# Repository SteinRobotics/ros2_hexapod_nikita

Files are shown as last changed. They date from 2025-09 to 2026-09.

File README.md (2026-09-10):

# Nikita Hexapod Robot (Maker Project)

**⚠️ WARNING: This repository is under heavy development! Breaking changes, incomplete features, and experimental code are expected. Use at your own risk. Contributions, feedback, and ideas are welcome.**

Nikita is an open-source, modular hexapod robot platform for makers, tinkerers, and robotics enthusiasts. The project is built around ROS2 and aims to be a flexible playground for learning, hacking, and experimenting with robotics and human-machine interaction. 

## Features & Goals
- **Maker Focus**: Designed for hands-on experimentation, learning, and creative robotics projects.
- **ROS2 Native**: Modern robotics workflows and easy integration with other ROS2 packages.
- **Modular Architecture**: Movement, communication, HMI, teleoperation, servo control, and more
- **Speech Recognition & Synthesis**: Online/offline STT and TTS with caching.
- **Flexible Gait & Kinematics**: Advanced gait controller and kinematics for smooth, stable walking and body pose control.
- **Teleoperation**: Joystick and remote control support.
- **Extensive Launch & Config**: Launch files and configuration options for different hardware and scenarios.
- **Diagnostics & Services**: Systemd integration and ROS2 topics for monitoring and diagnostics.

## Project Structure
- `nikita_brain/`         — High-level behavior, action planning, and coordination
- `nikita_movement/`      — Gait, kinematics, and movement primitives
- `nikita_communication/` — Speech recognition, TTS, chatbot, and audio I/O
- `nikita_hmi/`           — Human-machine interface (OLED, relay control)
- `nikita_teleop/`        — Teleoperation (joystick, remote)
- `nikita_lidar/`         — LIDAR sensor integration
- `nikita_navigation/`    — 1D-lidar head-sweep navigation with obstacle avoidance
- `nikita_interfaces/`    — Custom ROS2 message and service definitions
- `nikita_bringup/`       — Launch and bringup scripts
- `nikita_doc/`           — Documentation, diagrams, and hardware info
- `nikita_utils/`         — Shared utilities, math helpers, and tests
- `nikita_description/`   — URDF/XACRO robot model for visualization and simulation
- `nikita_gazebo/`        — Gazebo Harmonic simulation (gz-sim 8.x)

## Quick Start (for Makers)
1. **Install Dependencies**
   ```bash
   PIP_BREAK_SYSTEM_PACKAGES=1 rosdep install --from-paths ~/Workspace/colcon_nikita --ignore-src -r -y
   git submodule update --init --recursive
   ```
   If you want the simplest setup, keep using the full-workspace install above. If you want to split machines, the current package layout already allows two practical ROS setups:

   **Robot / headless target**
   - Intended for the Raspberry Pi or onboard computer.
   - Keeps runtime, sensor, audio, and hardware nodes.
   - Skips GUI and Gazebo packages such as `rviz2`, `joint_state_publisher_gui`, `ros_gz_sim`, and controller GUI tooling.
   ```bash
   PIP_BREAK_SYSTEM_PACKAGES=1 rosdep install -r -y --ignore-src \
     --from-paths \
       ~/Workspace/colcon_nikita/src/ros2_hexapod_nikita/nikita_interfaces \
       ~/Workspace/colcon_nikita/src/ros2_hexapod_nikita/nikita_utils \
       ~/Workspace/colcon_nikita/src/ros2_hexapod_nikita/nikita_movement \
       ~/Workspace/colcon_nikita/src/ros2_hexapod_nikita/nikita_brain \
       ~/Workspace/colcon_nikita/src/ros2_hexapod_nikita/nikita_communication \
       ~/Workspace/colcon_nikita/src/ros2_hexapod_nikita/nikita_hmi \
       ~/Workspace/colcon_nikita/src/ros2_hexapod_nikita/nikita_lidar \
       ~/Workspace/colcon_nikita/src/ros2_hexapod_nikita/nikita_navigation \
       ~/Workspace/colcon_nikita/src/ros2_hexapod_nikita/nikita_teleop \
       ~/Workspace/colcon_nikita/src/ros2_hexapod_nikita/nikita_bringup

   colcon build --symlink-install --packages-up-to nikita_bringup
   ```

   **Remote PC / simulation and GUI tools**
   - Intended for Gazebo, RViz, URDF inspection, and desktop debugging.
   - Keeps shared logic packages plus the visualization/simulation packages.
   - Can skip robot-only hardware packages such as `nikita_hmi` and usually `nikita_bringup`.
   ```bash
   PIP_BREAK_SYSTEM_PACKAGES=1 rosdep install -r -y --ignore-src \
     --from-paths \
       ~/Workspace/colcon_nikita/src/ros2_hexapod_nikita/nikita_interfaces \
       ~/Workspace/colcon_nikita/src/ros2_hexapod_nikita/nikita_utils \
       ~/Workspace/colcon_nikita/src/ros2_hexapod_nikita/nikita_movement \
       ~/Workspace/colcon_nikita/src/ros2_hexapod_nikita/nikita_brain \
       ~/Workspace/colcon_nikita/src/ros2_hexapod_nikita/nikita_communication \
       ~/Workspace/colcon_nikita/src/ros2_hexapod_nikita/nikita_navigation \
       ~/Workspace/colcon_nikita/src/ros2_hexapod_nikita/nikita_description \
       ~/Workspace/colcon_nikita/src/ros2_hexapod_nikita/nikita_gazebo

   colcon build --symlink-install \
     --packages-up-to nikita_gazebo nikita_description nikita_navigation
   ```

   Notes:
   - The split is already possible because the GUI-heavy dependencies are isolated mainly in `nikita_description` and `nikita_gazebo`, while `nikita_bringup` stays on the robot/runtime side.
   - Do not run `rosdep install --from-paths ...` over the entire workspace on the robot if you want a lean headless install, because that will pull the Gazebo and RViz dependencies too.
   - This is currently a documentation-level split, not a fully formalized profile system. If you later want stricter separation, the next step would be to introduce dedicated metapackages such as `nikita_robot` and `nikita_desktop`.
2. **Build the Workspace**
   ```bash
   colcon build --symlink-install
   source install/local_setup.bash
   ```
3. **Launch the Robot**
   ```bash
   ros2 launch nikita_bringup target_launch.py
   # with navigation enabled
   ros2 launch nikita_bringup target_launch.py enable_navigation:=true
   # or for testing
   ros2 launch nikita_bringup test_launch.py
   ```
4. **Launch Individual Components**
   ```bash
   ros2 launch nikita_brain brain_launch.py
   ros2 launch nikita_communication communication_launch.py
   ros2 launch nikita_movement movement_launch.py
   ros2 launch nikita_teleop teleop_launch.py
   ros2 launch nikita_lidar lidar_launch.yaml
   ros2 launch nikita_navigation navigation_launch.py
   # with map server
   ros2 launch nikita_navigation navigation_launch.py enable_map:=true
   ```
5. **Interact & Hack**
   - Send movement commands:
     ```bash
     ros2 topic pub --once /cmd_movement nikita_interfaces/msg/MovementRequest "..."
     ```
   - Monitor topics:
     ```bash
     ros2 topic list
     ros2 topic echo /servos_status
     ```
   - Speech commands:
     ```bash
     ros2 topic pub --once /speech_recognition_online std_msgs/msg/String "{data: 'steh auf'}"
     ```
   - Joystick/teleop:
     ```bash
     ros2 topic pub --once /joystick_request nikita_interfaces/msg/JoystickRequest "..."
     ```

## Simulation & Visualization

### Preview the Robot Model in RViz
Visualize the URDF model with interactive joint sliders — no Gazebo or hardware needed:
```bash
source install/setup.bash
ros2 launch nikita_description display.launch.py
```

To preview the CAD/STL-based model instead, use its separate launch file:
```bash
ros2 launch nikita_description display_mesh.launch.py
```
The original primitive model remains available through `display.launch.py`.

### Gazebo Simulation
Run the full hexapod simulation in Gazebo Harmonic:
```bash
# Install simulation dependencies (once)
sudo apt-get install ros-jazzy-gz-ros2-control ros-jazzy-controller-manager \
  ros-jazzy-joint-state-broadcaster ros-jazzy-forward-command-controller \
  ros-jazzy-joint-state-publisher-gui

# Navigation dependencies (optional)
sudo apt-get install ros-jazzy-nav2-map-server ros-jazzy-nav2-lifecycle-manager

# Build and launch
colcon build --symlink-install --packages-select nikita_description nikita_gazebo
source install/setup.bash
ros2 launch nikita_gazebo gazebo.launch.py

# Launch with the simple room world and navigation
ros2 launch nikita_gazebo simulation_gazebo.launch.py \
  world:=$(ros2 pkg prefix nikita_gazebo)/share/nikita_gazebo/worlds/simple_room.sdf \
  enable_navigation:=true
```

### Mesh Model in Gazebo
The mesh model has its own launch file and does not change the existing primitive-model simulation:
```bash
colcon build --symlink-install --packages-select nikita_description nikita_gazebo
source install/setup.bash
ros2 launch nikita_gazebo simulation_mesh.launch.py
```
This starts Gazebo Harmonic, spawns the STL-based robot, loads the existing 20-joint
controller configuration, and starts the joint-state broadcaster. The mesh model omits
head visuals but retains invisible head yaw and pitch joints for controller compatibility.

Command joints in the simulation (all 20 joints, values in radians):
```bash
ros2 topic pub /forward_position_controller/commands std_msgs/msg/Float64MultiArray \
  "{data: [0,0,0, 0,0,0, 0,0,0, 0,0,0, 0,0,0, 0,0,0, 0,0]}"
```

## Raspberry Pi 5 Pin Layout
The Raspberry Pi 5 inside Nikita hosts most of the human-machine interface hardware that lives in `nikita_hmi/`. The table follows the standard 40-pin header (odd numbers on the left when the USB ports face you). Pins with descriptions are currently wired up; empty cells are free for experiments.

| Pin | Signal | Usage | Pin | Signal | Usage |
| ----- | --- | --- | --- | --- | --- |
| **1** | 3V3 | supply for I2C modules | 2 | 5V | — |
| **3** | GPIO2 (SDA1)  | I2C bus | **4**  | 5V | Servo Power Relay |
| **5** | GPIO3 (SCL1)  | I2C bus | **6**  | GND | GND for I2C modules |
| 7 | GPIO4 | — | 8 | GPIO14 (TXD)  | — |
| 9 | GND | — | 10 | GPIO15 (RXD)  | — |
| 11 | GPIO17 | — | 12 | GPIO18 | — |
| 13 | GPIO27 | — | **14** | GND | Servo Power Relay |
| 15 | GPIO22 | — | 16 | GPIO23 | |
| 17 | 3V3 | — | 18 | GPIO24 | — |
| 19 | GPIO10 (MOSI) | — | 20 | GND | — |
| 21 | GPIO9 (MISO)  | — | 22 | GPIO25 | — |
| 23 | GPIO11 (SCLK) | — | 24 | GPIO8 (CE0) | — |
| 25 | GND | — | 26 | GPIO7 (CE1) | — |
| 27 | GPIO0 (ID_SD) | — | 28 | GPIO1 (ID_SC) | — |
| 29 | GPIO5 | — | 30 | GND | — |
| 31 | GPIO6 | — | 32 | GPIO12 | — |
| 33 | GPIO13 | — | **34** | GND | BNO055 I2C switch |
| 35 | GPIO19 | — | **36** | GPIO16 | Servo Power Relay |
| 37 | GPIO26 | — | 38 | GPIO20 | — |
| 39 | GND | — | 40 | GPIO21 | — |

### I2C Device Addresses
| Device | Address |
| --- | --- |
| BNO055 IMU | 0x29 |
| SSD1306 OLED Display | 0x3C |
| INA228 Power Monitor | 0x40 |
| Garmin Lidar Lite | 0x62 |

## Systemd Service (Optional)
To auto-start ROS2 on boot:
```bash
sudo systemctl start autostart_ros2
sudo systemctl status autostart_ros2
```

## Documentation
- See `nikita_doc/` for hardware pinouts, protocol docs, and setup guides.
- Diagrams and images are provided for wiring and architecture overview.

## Music
https://www.musicfox.com/info/kostenlose-gemafreie-musik/

## Contributing
This is a maker project—experimentation, hacking, and learning are encouraged! Contributions, bug reports, and feature requests are welcome. Please open issues or pull requests for improvements.

## License
Copyright (c) 2021-2025 Christian Stein

---

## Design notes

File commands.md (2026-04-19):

## service
```
sudo systemctl start autostart_ros2
sudo systemctl status autostart_ros2
```

## install dependencies
```
PIP_BREAK_SYSTEM_PACKAGES=1 rosdep install --from-paths ~/Workspace/colcon_nikita --ignore-src -r -y

python3 -m pip install lewansoul-lx16a --break-system-packages
python3 -m pip install lewansoul-lx16a-terminal --break-system-packages

git submodule update --init
```

## build
```
colcon build --symlink-install
colcon build --packages-up-to nikita_servo
```

```
source install/local_setup.bash
```

## log topics
```
ros2 topic list
ros2 topic echo --csv /servos_status
ros2 topic echo --once /servos_status
```

## send requests
```
ros2 topic pub --once /request_listening std_msgs/msg/Bool data:\ true

ros2 topic pub --once /speech_recognition_online std_msgs/msg/String data:\ "lauf nach vorne"

ros2 topic pub --once /speech_recognition_online std_msgs/msg/String "{data: 'steh auf'}"

ros2 topic pub --once /speech_recognition_online std_msgs/msg/String "{data: 'leg dich hin'}"

ros2 topic pub --once /speech_recognition_online std_msgs/msg/String data:\ "teste beine"

ros2 topic pub --once /request_music std_msgs/msg/String "{data: 'musicfox_hot_dogs_for_breakfast.mp3'}"

ros2 topic pub --once /joystick_request nikita_interfaces/msg/JoystickRequest "header:
  stamp:
    sec: 0
    nanosec: 0
  frame_id: ''
button_a: false
button_b: false
button_x: false
button_y: false
button_l1: false
button_l2: false
button_r1: false
button_r2: false
button_select: false
button_start: false
button_home: false
button_long_a: false
button_long_b: false
button_long_x: false
button_long_y: false
button_long_l1: false
button_long_l2: false
button_long_r1: false
button_long_r2: false
button_long_select: false
button_long_start: false
button_long_home: false
dpad_vertical: 0
dpad_horizontal: 0
left_stick_vertical: 0.50
left_stick_horizontal: 0.0
right_stick_horizontal: 0.0
right_stick_vertical: 0.0"
---

ros2 topic pub --once /cmd_vel geometry_msgs/msg/Twist "{linear: {x: 0.5, y: 0.0, z: 0.0}, angular: {x: 0.0, y: 0.0, z: 0.3}}"
---

ros2 topic pub --once /cmd_movement nikita_interfaces/msg/MovementRequest "header:
  stamp:
    sec: 0
    nanosec: 0
  frame_id: ''
type: 13
direction: 0
duration_s: 2.0
name: 'SEQUENCE_BODY_ROLL'
"
---

ros2 topic pub --once /cmd_movement nikita_interfaces/msg/MovementRequest "header:
  stamp:
    sec: 0
    nanosec: 0
  frame_id: ''
type: 4
direction: 0
duration_s: 1.0
name: ''
"

ros2 topic pub --once /cmd_movement nikita_interfaces/msg/MovementRequest "header:
  stamp:
    sec: 0
    nanosec: 0
  frame_id: ''
type: 20
direction: 0
duration_s: 1.0
name: 'CONTINUOUS_RUNNING'
"

ros2 topic pub --once /cmd_movement_update nikita_interfaces/msg/ContinuousMovementUpdate "header:
  stamp:
    sec: 0
    nanosec: 0
  frame_id: ''
velocity:
  linear: {x: 0.5, y: 0.0, z: 0.0}
  angular: {x: 0.0, y: 0.0, z: 0.0}
body_pose:
  position: {x: 0.0, y: 0.0, z: 0.0}
  orientation: {roll: 0.0, pitch: 0.0, yaw: 0.0}
head_orientation: {roll: 0.0, pitch: 0.0, yaw: 0.0}
"
---

ros2 topic echo --once /movement_type_actual
---

ros2 topic pub --once /servo_status nikita_interfaces/msg/ServoStatus "header:
  stamp:
    sec: 0
    nanosec: 0
  frame_id: ''
servo_error_code: 'LEG_LEFT_FRONT_COXA'
error_code: 0
servo_max_temperature: 'LEG_LEFT_FRONT_COXA'
max_temperature: 40.0
servo_max_voltage: 'LEG_LEFT_FRONT_COXA'
max_voltage: 12.0
servo_min_voltage: 'LEG_LEFT_FRONT_COXA'
min_voltage: 12.0
"
---

```
ros2 topic pub --once /single_servo_request nikita_interfaces/msg/ServoAngle "
  name: LEG_RIGHT_BACK_COXA 
  angle_deg: 0.0"
```

## launch robot
```
source install/local_setup.bash
ros2 launch nikita_bringup target_launch.py
ros2 launch nikita_bringup test_launch.py

ros2 launch nikita_brain brain_launch.py
ros2 launch nikita_communication communication_launch.py
ros2 launch nikita_movement movement_launch.py
ros2 launch nikita_servo servo_launch.py
ros2 launch nikita_teleop teleop_launch.py
ros2 launch nikita_lidar lidar_launch.yaml

#ros2 launch nikita_servo_controller servo_controller_launch.py

```

## remote computer

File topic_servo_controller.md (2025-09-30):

# topics of the node servo_controller 
```

ros2 topic pub --once /servo_status nikita_interfaces/msg/ServoStatus "header:
  stamp:
    sec: 0
    nanosec: 0
  frame_id: ''
servo_error_code: 'LEG_LEFT_FRONT_COXA'
error_code: 0
servo_max_temperature: 'LEG_LEFT_FRONT_COXA'
max_temperature: 40.0
servo_max_voltage: 'LEG_LEFT_FRONT_COXA'
max_voltage: 12.0
servo_min_voltage: 'LEG_LEFT_FRONT_COXA'
min_voltage: 12.0
"
```

## servo direct request
### set Servo ID
```
ros2 topic pub --once /servo_direct_request nikita_interfaces/msg/ServoDirectRequest "
name: 'LEG_LEFT_FRONT_COXA'
cmd: 13
data1: 10
data2: 0
"
```

ros2 topic pub --once /servo_request nikita_interfaces/msg/ServoRequest "header:
  stamp:
    sec: 0
    nanosec: 0
  frame_id: ''
target_angles:
- name: 'HEAD_YAW'
  angle_deg: 0.0
- name: 'HEAD_PITCH'
  angle_deg: 0.0
- name: 'LEG_LEFT_FRONT_COXA'
  angle_deg: 0.0
- name: 'LEG_LEFT_FRONT_FEMUR'
  angle_deg: 20.0
- name: 'LEG_LEFT_FRONT_TIBIA'
  angle_deg: 20.0
- name: 'LEG_LEFT_MID_COXA'
  angle_deg: 0.0
- name: 'LEG_LEFT_MID_FEMUR'
  angle_deg: 0.0
- name: 'LEG_LEFT_MID_TIBIA'
  angle_deg: 0.0
- name: 'LEG_LEFT_BACK_COXA'
  angle_deg: 0.0
- name: 'LEG_LEFT_BACK_FEMUR'
  angle_deg: 0.0
- name: 'LEG_LEFT_BACK_TIBIA'
  angle_deg: 0.0
- name: 'LEG_RIGHT_FRONT_COXA'
  angle_deg: 0.0
- name: 'LEG_RIGHT_FRONT_FEMUR'
  angle_deg: 0.0
- name: 'LEG_RIGHT_FRONT_TIBIA'
  angle_deg: 0.0
- name: 'LEG_RIGHT_MID_COXA'
  angle_deg: 0.0
- name: 'LEG_RIGHT_MID_FEMUR'
  angle_deg: 0.0
- name: 'LEG_RIGHT_MID_TIBIA'
  angle_deg: 0.0
- name: 'LEG_RIGHT_BACK_COXA'
  angle_deg: 0.0
- name: 'LEG_RIGHT_BACK_FEMUR'
  angle_deg: 0.0
- name: 'LEG_RIGHT_BACK_TIBIA'
  angle_deg: 0.0
time_to_reach_target_angles_ms: 3000"
```

```
ros2 topic pub --once /single_servo_request nikita_interfaces/msg/ServoAngle "
  name: LEG_RIGHT_BACK_COXA 
  angle_deg: 0.0"
```

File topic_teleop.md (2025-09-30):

# send requests

## stehe auf:
```
ros2 topic pub --once /joystick_request nikita_interfaces/msg/JoystickRequest "header:
  stamp:
    sec: 0
    nanosec: 0
  frame_id: ''
button_a: false
button_b: false
button_x: false
button_y: false
button_l1: false
button_l2: false
button_r1: false
button_r2: false
button_select: false
button_start: false
dpad_vertical: 1
dpad_horizontal: 0
left_stick_vertical: 0.0
left_stick_horizontal: 0.0
right_stick_horizontal: 0.0
right_stick_vertical: 0.0"
```

## cyclic movement
```
ros2 topic pub --rate 10 /joystick_request nikita_interfaces/msg/JoystickRequest "header:
  stamp:
    sec: 0
    nanosec: 0
  frame_id: ''
button_a: false
button_b: false
button_x: false
button_y: false
button_l1: false
button_l2: false
button_r1: false
button_r2: false
button_select: false
button_start: false
dpad_vertical: 0
dpad_horizontal: 0
left_stick_vertical: 0.4
left_stick_horizontal: 0.0
right_stick_horizontal: 0.0
right_stick_vertical: 0.0"
```
```
ros2 topic pub --once /joystick_request nikita_interfaces/msg/JoystickRequest "header:
  stamp:
    sec: 0
    nanosec: 0
  frame_id: ''
button_a: false
button_b: false
button_x: false
button_y: false
button_l1: false
button_l2: false
button_r1: false
button_r2: false
button_select: false
button_start: false
dpad_vertical: 0
dpad_horizontal: 0
left_stick_vertical: 0.0
left_stick_horizontal: 0.0
right_stick_horizontal: 0.0
right_stick_vertical: 0.0"
```

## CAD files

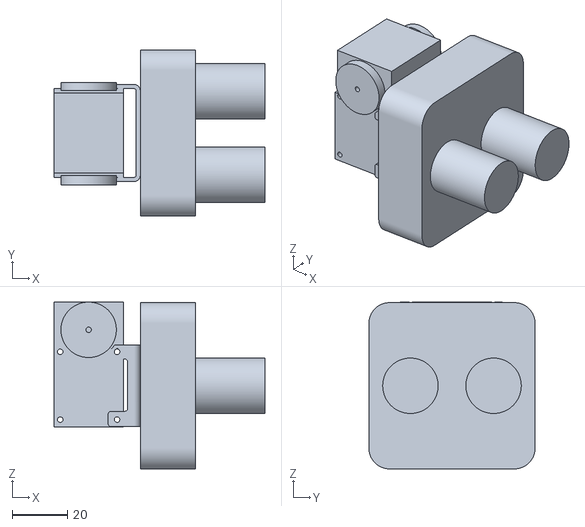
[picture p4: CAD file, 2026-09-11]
nikita_description/meshes/assembly_head.stl
76.1 x 60.0 x 60.2

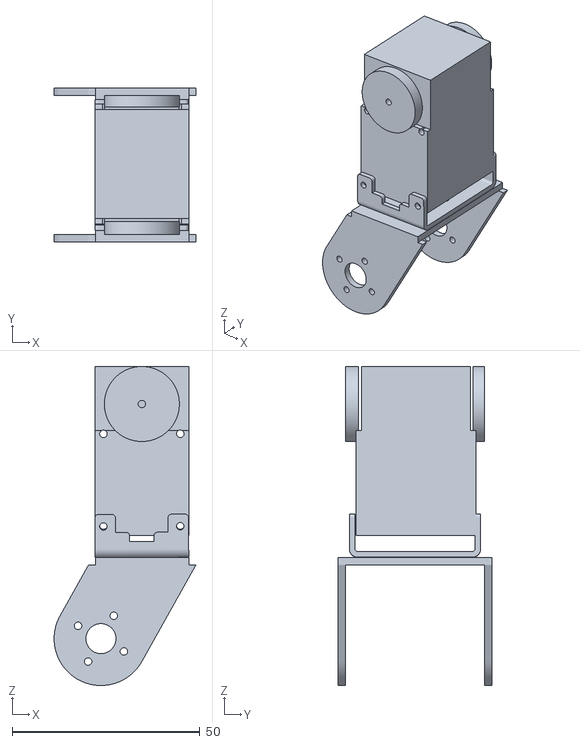
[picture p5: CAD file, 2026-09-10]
nikita_description/meshes/assembly_femur.stl
37.8 x 41.0 x 85.1

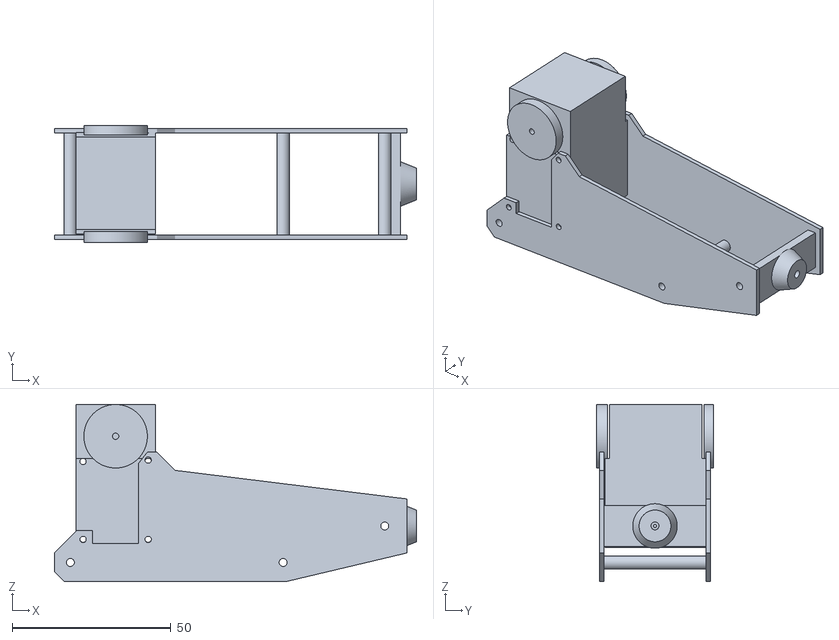
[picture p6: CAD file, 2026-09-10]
nikita_description/meshes/assembly_tibia.stl
114.0 x 37.0 x 55.8

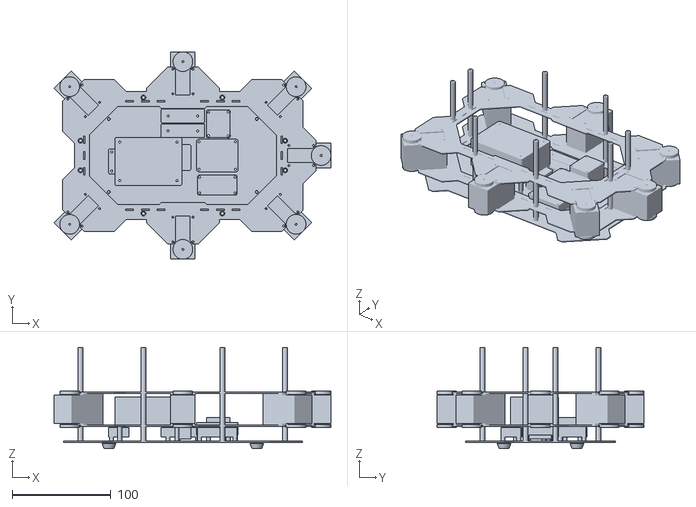
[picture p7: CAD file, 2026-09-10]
nikita_description/meshes/assembly_body_servo.stl
280.9 x 210.4 x 102.5

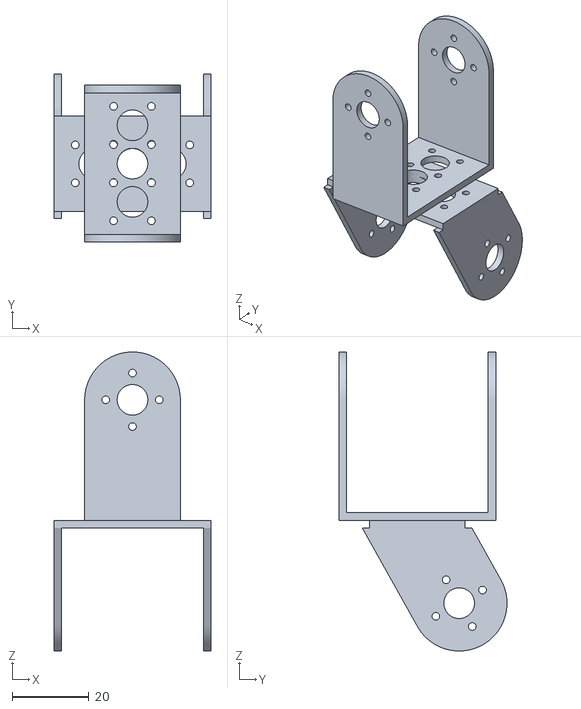
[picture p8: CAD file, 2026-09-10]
nikita_description/meshes/assembly_coxa.stl
41.0 x 43.9 x 78.1

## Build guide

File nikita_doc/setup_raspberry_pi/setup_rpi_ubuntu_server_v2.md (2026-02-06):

# Initial Setup
## WiFi Connection
```
sudo cat /etc/netplan/50-cloud-init.yaml
__
network:
  version: 2
  wifis:
    wlan0:
      optional: true
      dhcp4: true
      access-points:
        "XXXXXXXXXXXX":
          auth:
            key-management: "psk"
            password: "YYYYYYYYYYYYY"
        "InnoWorX_1":
          password: "AAAAAA"
        "ChristianHotspot":
          password: "AAAAAA"

__

sudo apt update
sudo apt upgrade
sudo reboot
sudo shutdown -h now
mkdir Workspace
```

____
## install Workspace
### install ROS2
```
mkdir colcon_nikita
cd colcon_nikita/
mkdir src
cd src/
locale  # check for UTF-8
sudo apt update && sudo apt install locales
sudo locale-gen en_US en_US.UTF-8
sudo update-locale LC_ALL=en_US.UTF-8 LANG=en_US.UTF-8
export LANG=en_US.UTF-8
locale  # verify settings
sudo apt install software-properties-common
sudo add-apt-repository universe
sudo apt update && sudo apt install curl -y
export ROS_APT_SOURCE_VERSION=$(curl -s https://api.github.com/repos/ros-infrastructure/ros-apt-source/releases/latest | grep -F "tag_name" | awk -F\" '{print $4}')
curl -L -o /tmp/ros2-apt-source.deb "https://github.com/ros-infrastructure/ros-apt-source/releases/download/${ROS_APT_SOURCE_VERSION}/ros2-apt-source_${ROS_APT_SOURCE_VERSION}.$(. /etc/os-release && echo ${UBUNTU_CODENAME:-${VERSION_CODENAME}})_all.deb"
sudo dpkg -i /tmp/ros2-apt-source.deb
sudo apt update && sudo apt install ros-dev-tools
sudo apt update
sudo apt upgrade
sudo apt install ros-kilted-ros-base
```

### install nikita 
```
git clone https://github.com/SteinRobotics/ros2_hexapod_nikita.git
cd ros2_hexapod_nikita/
git checkout develop 
git pull
sudo rosdep init
rosdep update
sudo apt install python3-pip
PIP_BREAK_SYSTEM_PACKAGES=1 rosdep install --from-paths ~/Workspace/colcon_nikita --ignore-src -r -y
git clone https://github.com/garmin/LIDARLite_RaspberryPi_Library.git
sudo apt install libmagicenum-dev
nano ~/Workspace/colcon_nikita/src/ros2_hexapod_nikita/nikita_lidar/src/LIDARLite_RaspberryPi_Library/include/lidarlite_v3.h 
colcon build --symlink-install
source /opt/ros/kilted/setup.bash
source ~/.bashrc
```

### install dependencies
```
sudo apt install python3-pygame
python3 -m pip install --break-system-packages vosk pyttsx3 google-api-python-client google-cloud-speech oauth2client sounddevice SpeechRecognition pyyaml
sudo apt install -y portaudio19-dev python3-pyaudio
sudo pip3 install adafruit-circuitpython-ssd1306 --break-system-packages
sudo pip3 install adafruit-circuitpython-bno055 --break-system-packages
```

___
## Sound settings:
```
wpctl get-volume @DEFAULT_AUDIO_SINK@
wpctl set-volume @DEFAULT_AUDIO_SINK@ 0.90
wpctl status
```
___  
## No PW
```
sudo visudo
nikita ALL=(ALL) NOPASSWD: /sbin/shutdown, /sbin/restart, /usr/sbin/reboot, /bin/systemctl start autostart_ros2.service, /bin/systemctl stop autostart_ros2.service, /bin/systemctl status autostart_ros2.service
```

## Autostart Service
sudo loginctl enable-linger nikita

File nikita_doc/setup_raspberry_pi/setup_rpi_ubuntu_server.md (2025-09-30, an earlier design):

    4  sudo dpkg-reconfigure keyboard-configuration
    5  reboot
    6  sudo nano /etc/netplan/50-cloud-init.yaml
    7  reboot
   13  sudo netplan --debug try
   15  sudo netplan --debug generate
   16  sudo netplan --debug apply
   18  reboot
   27  networkctl
   28  ping google.de
   29  sudo apt update
   30  sudo apt upgrade
   31  sudo apt autoremove
   32  sudo apt clean
   49  cd .ssh/
   57  ssh-keygen
   58  ls ~/.ssh/
   59  cat  ~/.ssh/id_ed25519.pub
   60  ssh alexej@lapi
   62  scp /home/ubuntu/.ssh/id_ed25519.pub alexej@lapi:/home/alexej/
   72  sudo apt install python-is-python3
   75  sudo apt install python3-pip
   80  scp alexej@lapi:~/.ssh/id_rsa.pub ~/
   83  cat id_rsa.pub  > ~/.ssh/authorized_keys
   86  sudo apt install -y i2c-tools python3-smbus
   88  sudo i2cdetect -y 1
   91  journalctl
   93  pip3 install adafruit-circuitpython-bno055 --break-system-packages
   95  sudo apt install python3-libgpiod
  100  cat /etc/udev/rules.d/90-gpio.rules
  103  sudo touch /etc/udev/rules.d/90-gpio.rules
  105  sudo nano /etc/udev/rules.d/90-gpio.rules
  106  sudo groupadd -f --system gpio
  107  sudo usermod -a -G gpio ubuntu
  118  sudo groupadd -f --system i2c
  119  sudo usermod -a -G i2c ubuntu
  125  ifconfig
  126  ip addr
  129  groups
  148  git clone git@bitbucket.org:steinrobotics/ros2_nikita.git
  153  sudo vcgencmd measure_temp
  155  journalctl
  157  sudo dmesg -w
  163  sudo apt-get install pulseaudio
  168  sudo apt install alsa-base
  175  sudo alsamixer
  182  pip3 install terminalio --break-system-packages
  185  pip3 install adafruit-circuitpython-ssd1306 --break-system-packages
  190  sudo usermod -aG audio ubuntu
  191  sudo aplay /usr/share/sounds/alsa/Front_Center.wav

____

place 90-gpio.rules at /etc/udev/rules.d/90-gpio.rules

____

pactl set-sink-volume alsa_output.usb-Jieli_Technology_UACDemoV1.0_503581119377601F-00.analog-stereo 70%
pactl set-source-volume alsa_input.usb-C-Media_Electronics_Inc._USB_PnP_Sound_Device-00.analog-mono 100%

____

sudo visudo
nikita ALL=(ALL) NOPASSWD: /sbin/shutdown, /sbin/restart, /bin/systemctl start autostart_ros2.service, /bin/systemctl stop autostart_ros2.service

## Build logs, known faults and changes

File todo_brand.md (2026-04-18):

Name
RumblingRobotics

RobotNames:
The Rumblers
RumbleBots

TShirt:
https://www.shirtinator.de
https://www.shirt-king.de/

webpage:
https://www.jimdo.com/de/

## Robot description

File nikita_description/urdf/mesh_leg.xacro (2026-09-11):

<?xml version="1.0"?>
<robot xmlns:xacro="http://www.ros.org/wiki/xacro">

  <!--
    Mesh leg variant.  The CAD exports are in millimetres and use the
    assembly joint as their local reference.  The small origins below are
    deliberately explicit: they document the CAD-to-URDF registration and
    keep the joint frames identical to leg.xacro.
  -->
  <xacro:macro name="mesh_hexapod_leg" params="prefix cx cy psi_deg">
    <xacro:property name="mount_yaw" value="${psi_deg * pi / 180.0 - pi / 2.0}"/>
    <xacro:property name="mesh_scale" value="0.001 0.001 0.001"/>

    <joint name="${prefix}_coxa_joint" type="revolute">
      <parent link="base_link"/>
      <child link="${prefix}_coxa_link"/>
      <origin xyz="${cx} ${cy} ${coxa_height}" rpy="0 0 ${mount_yaw}"/>
      <axis xyz="0 0 -1"/>
      <limit lower="${-60 * pi / 180}" upper="${60 * pi / 180}" effort="3.0" velocity="6.0"/>
      <dynamics damping="0.1" friction="0.05"/>
    </joint>
    <link name="${prefix}_coxa_link">
      <visual>
        <origin xyz="0 0.035 -0.01" rpy="${pi / 2.0} 0 0"/>
        <geometry><mesh filename="package://nikita_description/meshes/assembly_coxa.stl" scale="${mesh_scale}"/></geometry>
        <material name="orange"/>
      </visual>
      <collision><origin xyz="0 ${coxa_length / 2.0} 0" rpy="${pi / 2.0} 0 0"/><geometry><box size="0.030 0.050 0.045"/></geometry></collision>
      <inertial><origin xyz="0 ${coxa_length / 2.0} 0"/><mass value="0.12"/><inertia ixx="3.0e-05" ixy="0" ixz="0" iyy="3.0e-05" iyz="0" izz="3.0e-05"/></inertial>
    </link>

    <joint name="${prefix}_femur_joint" type="revolute">
      <parent link="${prefix}_coxa_link"/><child link="${prefix}_femur_link"/>
      <origin xyz="0 ${coxa_length} 0" rpy="${30 * pi / 180} 0 0"/><axis xyz="1 0 0"/>
      <limit lower="${-30 * pi / 180}" upper="${90 * pi / 180}" effort="3.0" velocity="6.0"/>
      <dynamics damping="0.1" friction="0.05"/>
    </joint>
    <link name="${prefix}_femur_link">
      <visual>
        <origin xyz="0.015 0.043 0" rpy="${-90 * pi / 180} ${-90 * pi / 180} ${180 * pi / 180}"/>
        <geometry><mesh filename="package://nikita_description/meshes/assembly_femur.stl" scale="${mesh_scale}"/></geometry>
        <material name="dark_blue"/>
      </visual>
      <collision><origin xyz="0 ${femur_length / 2.0} 0" rpy="${-pi / 2.0} 0 0"/><geometry><box size="0.030 0.063 0.045"/></geometry></collision>
      <inertial><origin xyz="0 ${femur_length / 2.0} 0"/><mass value="0.12"/><inertia ixx="4.0e-05" ixy="0" ixz="0" iyy="4.0e-05" iyz="0" izz="4.0e-05"/></inertial>
    </link>

    <joint name="${prefix}_tibia_joint" type="revolute">
      <parent link="${prefix}_femur_link"/><child link="${prefix}_tibia_link"/>
      <origin xyz="0 ${femur_length} 0" rpy="${-120 * pi / 180} 0 0"/><axis xyz="1 0 0"/>
      <limit lower="${-90 * pi / 180}" upper="${90 * pi / 180}" effort="3.0" velocity="6.0"/>
      <dynamics damping="0.1" friction="0.05"/>
    </joint>
    <link name="${prefix}_tibia_link">
      <visual>
        <origin xyz="-0.015 0.04 0" rpy="${-90 * pi / 180} ${90 * pi / 180} ${180 * pi / 180}"/>
        <geometry><mesh filename="package://nikita_description/meshes/assembly_tibia.stl" scale="${mesh_scale}"/></geometry>
        <material name="light_blue"/>
      </visual>
      <collision><origin xyz="0 ${tibia_length / 2.0} 0" rpy="${-pi / 2.0} 0 0"/><geometry><box size="0.025 0.099 0.040"/></geometry></collision>
      <inertial><origin xyz="0 ${tibia_length / 2.0} 0"/><mass value="0.10"/><inertia ixx="4.0e-05" ixy="0" ixz="0" iyy="4.0e-05" iyz="0" izz="4.0e-05"/></inertial>
    </link>

    <joint name="${prefix}_foot_joint" type="fixed"><parent link="${prefix}_tibia_link"/><child link="${prefix}_foot"/><origin xyz="0 ${tibia_length} 0"/></joint>
    <link name="${prefix}_foot">
      <visual><geometry><sphere radius="0.006"/></geometry><material name="black"/></visual>
      <collision><geometry><sphere radius="0.006"/></geometry></collision>
      <inertial><mass value="0.005"/><inertia ixx="7.2e-08" ixy="0" ixz="0" iyy="7.2e-08" iyz="0" izz="7.2e-08"/></inertial>
    </link>
    <gazebo reference="${prefix}_foot"><mu1>1.0</mu1><mu2>1.0</mu2></gazebo>
  </xacro:macro>
</robot>

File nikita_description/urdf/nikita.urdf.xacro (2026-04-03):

<?xml version="1.0"?>
<robot xmlns:xacro="http://www.ros.org/wiki/xacro" name="nikita">

  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
  <xacro:include filename="$(find nikita_description)/urdf/materials.xacro"/>
  <xacro:include filename="$(find nikita_description)/urdf/leg.xacro"/>
  <xacro:include filename="$(find nikita_description)/urdf/ros2_control.xacro"/>

  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
  <xacro:property name="coxa_length" value="0.050"/>
  <xacro:property name="femur_length" value="0.063"/>
  <xacro:property name="tibia_length" value="0.099"/>
  <xacro:property name="coxa_height" value="0.045"/>

  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
  <xacro:property name="body_length" value="0.240"/>
  <xacro:property name="body_width" value="0.180"/>
  <xacro:property name="body_height" value="0.025"/>
  <xacro:property name="body_mass" value="0.400"/>

  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
  <xacro:arg name="use_sim" default="false"/>

  <xacro:if value="$(arg use_sim)">
    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
    <xacro:nikita_ros2_control/>
  </xacro:if>

  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
  <link name="base_link">
    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
    <inertial>
      <origin xyz="0 0 0.020"/>
      <mass value="${body_mass}"/>
      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
    </inertial>
  </link>

  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
  <joint name="imu_joint" type="fixed">
    <parent link="base_link"/>
    <child link="imu_link"/>
    <origin xyz="0 0 0.0075" rpy="0 0 0"/>
  </joint>

  <link name="imu_link">
    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
    <inertial>
      <mass value="0.003"/>
      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
    </inertial>
  </link>

  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
  <xacro:hexapod_leg prefix="right_front" cx="0.109" cy="0.068" psi_deg="45.0"/>
  <xacro:hexapod_leg prefix="right_mid" cx="0.000" cy="0.088" psi_deg="90.0"/>
  <xacro:hexapod_leg prefix="right_back" cx="-0.109" cy="0.068" psi_deg="135.0"/>

  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
  <xacro:hexapod_leg prefix="left_front" cx="0.109" cy="-0.068" psi_deg="-45.0"/>
  <xacro:hexapod_leg prefix="left_mid" cx="0.000" cy="-0.088" psi_deg="-90.0"/>
  <xacro:hexapod_leg prefix="left_back" cx="-0.109" cy="-0.068" psi_deg="-135.0"/>

  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
  <joint name="head_yaw_joint" type="revolute">
    <parent link="base_link"/>
    <child link="head_yaw_link"/>
    <origin xyz="0.130 0 ${coxa_height}" rpy="0 0 0"/>
    <axis xyz="0 0 1"/>
    <limit lower="${-30 * pi / 180}" upper="${30 * pi / 180}" effort="1.5" velocity="4.0"/>
    <dynamics damping="0.05" friction="0.02"/>
  </joint>

  <link name="head_yaw_link">
    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
    <inertial>
      <origin xyz="0 0 0.010"/>
      <mass value="0.025"/>
      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
    </inertial>
  </link>

  <joint name="head_pitch_joint" type="revolute">
    <parent link="head_yaw_link"/>
    <child link="head_pitch_link"/>
    <origin xyz="0 0 0.020" rpy="0 0 0"/>
    <axis xyz="0 1 0"/>
    <limit lower="${-20 * pi / 180}" upper="${20 * pi / 180}" effort="1.5" velocity="4.0"/>
    <dynamics damping="0.05" friction="0.02"/>
  </joint>

  <link name="head_pitch_link">
    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
    <inertial>
      <origin xyz="0.015 0 0"/>
      <mass value="0.025"/>
      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
    </inertial>
  </link>

  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
  <joint name="lidar_joint" type="fixed">
    <parent link="head_pitch_link"/>
    <child link="lidar_link"/>
    <origin xyz="0.030 0 0" rpy="0 0 0"/>
  </joint>

  <link name="lidar_link">
    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
    <inertial>
      <origin xyz="0.020 0 0"/>
      <mass value="0.022"/>
      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
    </inertial>
  </link>

  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

</robot>

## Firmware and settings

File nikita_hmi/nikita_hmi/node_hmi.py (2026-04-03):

#!/usr/bin/env python3
# -*- coding: utf-8 -*-

__copyright__ = "Copyright (C) 2025 Christian Stein"
__license__ = "MIT"

import subprocess
import time
import socket

import rclpy
from rclpy.node import Node
from std_msgs.msg import Bool, Float32
from sensor_msgs.msg import Imu, Range
from nikita_interfaces.msg import MovementRequest
from nikita_interfaces.msg import ServoStatus
from nikita_interfaces.msg import JoystickRequest

from PIL import Image, ImageDraw, ImageFont

import board
from digitalio import DigitalInOut
import adafruit_ssd1306
import adafruit_ina228


class NodeHmi(Node):
    NUMBER_OF_LINES = 6

    def __init__(self):
        super().__init__('node_hmi')
        self.is_ip_address_identified = False
        self.timeout_identifying_ip_address = 60

        # System display text lines
        self.text_ip_address = ""  # line number 1
        self.text_movement_request = ""  # line number 2
        self.text_supply_voltage_and_current = ""  # line number 3
        self.text_cpu_temperature = ""  # line number 4
        
        # Servo text lines
        self.text_servo_relay_status = ""  # line number 1
        self.text_servo_name = ""  # line number 2
        self.text_servo_max_temperature = ""  # line number 3
        self.text_servo_min_voltage = ""  # line number 4

        # Sensor text lines
        self.text_listening_active = ""  # line number 1
        self.text_bno055 = ""  # line number 2
        self.text_lidar = ""  # line number 3

        self.active_page_name = 'system'
        self.page_orders = ['system', 'servos', 'sensors']

        self.display_old_values = ["" for x in range(self.NUMBER_OF_LINES)]  # store the last texts to be able to overwrite them with black before writing new text

        # Servo Relay
        self.relay_pin = DigitalInOut(board.D16) # GPIO_16, physical pin 36  
        self.relay_pin.switch_to_output()
        self.relay_pin.value = False # turn relay off

        self.i2c = board.I2C()
        self.display = adafruit_ssd1306.SSD1306_I2C(128, 64, self.i2c)
        self.display.fill(0)
        self.display.show()
        self.image = Image.new("1", (self.display.width, self.display.height))
        self.draw = ImageDraw.Draw(self.image)
        self.font = ImageFont.truetype("/usr/share/fonts/truetype/liberation/LiberationSans-Regular.ttf", 12)

        self.__ina228 = adafruit_ina228.INA228(self.i2c)
        time.sleep(0.5)

        # turn relay on
        self.relay_pin.value = True

        self.create_subscription(Range, 'scan_1d', self.callback_lidar, 10)
        self.create_subscription(Bool, 'request_servo_relay', self.callback_servo_relay, 10)
        self.create_subscription(Bool, 'request_system_shutdown', self.callback_system_shutdown, 10)
        self.create_subscription(MovementRequest, 'movement_type_actual', self.callback_movement_type, 10)
        self.create_subscription(ServoStatus, 'servo_status', self.callback_servo_status, 10)
        self.create_subscription(JoystickRequest, 'joystick_request', self.callback_joystick_request, 10)
        self.create_subscription(Imu, 'bno055/imu', self.callback_imu, 10)
        self.pub_supply_voltage = self.create_publisher(Float32, 'supply_voltage', 10)

        # TODO TEST easier like this self.font_height = 10 + 2
        (self.font_width, self.font_height) = self.font.getmask("SYSTEM").size
        self.font_height += 3
        self.update_display("SYSTEM", 0)

        timer_period = 1.0  # seconds
        self.timer = self.create_timer(timer_period, self.timer_callback)

    def update_display(self, text, line_number=0):
        # first overwrite the old text with the same text in black
        self.draw.text((0, self.font_height * line_number), self.display_old_values[line_number], font=self.font, fill=0)
        # then write the new text in white
        self.draw.text((0, self.font_height * line_number), text, font=self.font, fill=255)
        self.display.image(self.image)
        self.display.show()
        # update the text 
        self.display_old_values[line_number] = text

    def get_ip_address(self):
        ip_address = "0.0.0.0"
        try:
            with socket.socket(socket.AF_INET, socket.SOCK_DGRAM) as s:
                s.connect(("8.8.8.8",80))
                ip_address = s.getsockname()[0]
            self.is_ip_address_identified = True
        except Exception as e:
            self.get_logger().warning('Could not get IP address, error: %s' % e)
            ip_address = "0.0.0.0"  # fallback

        self.get_logger().info('IP address: %s' % ip_address)
        return ip_address

    def get_page_data(self, page_name):
        if page_name == 'system':
            return [
                "SYSTEM",
                self.text_ip_address,
                self.text_movement_request,
                self.text_supply_voltage_and_current,
                self.text_cpu_temperature,
                ""
            ]
        elif page_name == 'servos':
            return [
                "SERVOS",
                self.text_servo_relay_status,
                self.text_servo_name,
                self.text_servo_max_temperature,
                self.text_servo_min_voltage,
                ""
            ]
        elif page_name == 'sensors':
            return [
                "SENSORS",
                self.text_listening_active,
                self.text_bno055,
                self.text_lidar,
                "",
                ""
            ]
        return [""] * self.NUMBER_OF_LINES

    def update_active_page(self):
        page_data = self.get_page_data(self.active_page_name)
        for line_number, text in enumerate(page_data):
            self.update_display(text, line_number)

    def update_ip_address(self):
        if self.is_ip_address_identified:
            return
        
        if not self.is_ip_address_identified and self.timeout_identifying_ip_address > 0:
            self.timeout_identifying_ip_address -= 1
            ip_address = self.get_ip_address()
            self.text_ip_address  = "IP: " + ip_address

    def callback_imu(self, msg):
        gz = msg.linear_acceleration.z
        self.text_bno055 = f"g: {gz:.2f}m/s^2"

    def update_ina228(self):
        voltage = self.__ina228.bus_voltage
        current = self.__ina228.current
        if voltage is None or current is None:
            return
        current = abs(current)
        self.text_supply_voltage_and_current = f"supply V: {voltage:.1f}V I: {current:.1f}A"
        # publish supply voltage
        msg = Float32()
        msg.data = voltage
        self.pub_supply_voltage.publish(msg)

    def timer_callback(self):
        self.update_ip_address()
        self.update_ina228()
        self.update_active_page()

    def callback_lidar(self, msg):
        self.text_lidar = f"d: {msg.range:>5.2f}m"   # right justified, 5 characters wide, 2 decimal places

    def callback_movement_type(self, msg):
        self.text_movement_request = msg.name.lower()

    def callback_servo_status(self, msg):
        self.text_servo_name = f"{msg.servo_max_temperature.lower()}"
        self.text_servo_min_voltage = f"U: {msg.min_voltage:.1f}V" 
        self.text_servo_max_temperature = f"T: {msg.max_temperature:.1f}°C"

    def callback_servo_relay(self, msg):
        self.get_logger().info('callback_servo_relay: %s' % msg.data)
        self.text_servo_relay_status = "RELAY ON" if msg.data else "RELAY OFF"
        if msg.data:
            self.relay_pin.value = True
        else:
            self.relay_pin.value = False

    def callback_joystick_request(self, msg):
        if msg.button_select:
            self.draw.rectangle((0, 0, self.display.width, self.display.height), fill=0)
            self.display_old_values = ["" for _ in range(self.NUMBER_OF_LINES)]
            idx = self.page_orders.index(self.active_page_name)
            self.active_page_name = self.page_orders[(idx + 1) % len(self.page_orders)]
            self.update_active_page()
    
    def callback_system_shutdown(self, msg):
        self.get_logger().info('callback_system_shutdown: %s' % msg.data)
        if msg.data:
            self.shutdown_callback()
            time.sleep(1)
            self.get_logger().info('3')
            time.sleep(1)
            self.get_logger().info('2')
            time.sleep(1)
            self.get_logger().info('1')
            time.sleep(1)
            subprocess.call("sudo shutdown -h now", shell=True)  # sudo visudo ->  nikita ALL=(ALL) NOPASSWD: /sbin/shutdown

    def shutdown_callback(self):
        self.get_logger().info("shutdown_callback")
        self.relay_pin.value = False
        self.text_movement_request = "!!SHUTDOWN!!"
        self.active_page_name = 'system'
        self.update_active_page()


def main(args=None):
    rclpy.init(args=args)
    node_hmi = NodeHmi()

    try:
        rclpy.spin(node_hmi)  # Spin the node to process callbacks
    except KeyboardInterrupt:
        node_hmi.get_logger().info("Node interrupted by user.")
    finally:
        node_hmi.shutdown_callback()
        node_hmi.destroy_node()
        rclpy.shutdown()


if __name__ == '__main__':
    main()

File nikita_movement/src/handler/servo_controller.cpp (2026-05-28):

/*******************************************************************************
 * Copyright (c) 2023 Christian Stein
 ******************************************************************************/

// Servo Layout
//
//            020
//            010
//             |
// 036-026-016-|-011-021-031
//             |
// 035-025-015-|-012-022-032
//             |
// 034-024-014-|-013-023-033
//

#include "handler/servo_controller.hpp"

#include <algorithm>
#include <cctype>
#include <chrono>
#include <cmath>
#include <functional>
#include <memory>
#include <thread>

#include "handler/feetech_protocol.hpp"
#include "handler/hiwonder_protocol.hpp"
#include "handler/leg_servo_conversion.hpp"
#include "handler/offline_servo_protocol.hpp"
using namespace std::chrono_literals;
using nikita_interfaces::msg::ServoAngle;
using nikita_interfaces::msg::ServoAngles;
using nikita_interfaces::msg::ServoDirectRequest;
using nikita_interfaces::msg::ServoStatus;
using std::placeholders::_1;

namespace nikita_movement {

namespace {

constexpr auto kServoControllerTypeParam = "SERVO_CONTROLLER_TYPE";
constexpr auto kHiwonderServoControllerType = "hiwonder";
constexpr auto kFeetechServoControllerType = "feetech";

std::string normalizeServoControllerType(std::string controllerType) {
    std::transform(controllerType.begin(), controllerType.end(), controllerType.begin(),
                   [](unsigned char character) { return static_cast<char>(std::tolower(character)); });
    return controllerType;
}

std::shared_ptr<CServoProtocol> createServoProtocol(const std::shared_ptr<rclcpp::Node>& node,
                                                    const std::string& serialPort,
                                                    const bool isServoControllerOffline,
                                                    const std::string& servoControllerType) {
    if (isServoControllerOffline) {
        RCLCPP_INFO_STREAM(node->get_logger(),
                           "CServoController: using offline protocol for servo controller type '"
                               << servoControllerType << "'");
        return std::make_shared<COfflineServoProtocol>(node, serialPort);
    }

    if (servoControllerType == kHiwonderServoControllerType) {
        return std::make_shared<CHiwonderProtocol>(node, serialPort);
    }

    if (servoControllerType == kFeetechServoControllerType) {
        return std::make_shared<CFeetechProtocol>(node, serialPort);
    }

    RCLCPP_ERROR_STREAM(node->get_logger(), "CServoController: unsupported SERVO_CONTROLLER_TYPE='"
                                                << servoControllerType << "'. Supported values are '"
                                                << kHiwonderServoControllerType << "' and '"
                                                << kFeetechServoControllerType << "'");
    return nullptr;
}

}  // namespace

CServoController::CServoController(std::shared_ptr<rclcpp::Node> node) : node_(node) {
    cycleCounter_ = 0;

    RCLCPP_INFO_STREAM(node_->get_logger(), "CServoController: initializing connection...");

    std::string serialPort = node_->declare_parameter<std::string>("SERIAL_PORT", "/dev/ttyUSB0");

    std::string servoControllerType = normalizeServoControllerType(
        node_->declare_parameter<std::string>(kServoControllerTypeParam, kHiwonderServoControllerType));

    bool isServoControllerOffline = node_->declare_parameter<bool>("SERVO_CONTROLLER_OFFLINE", false);

    std::vector<std::string> names =
        node_->declare_parameter<std::vector<std::string>>("SERVO_NAME", std::vector<std::string>());

    std::vector<double> adaptations =
        node_->declare_parameter<std::vector<double>>("SERVO_ADAPTATION_DEG", std::vector<double>());

    std::vector<double> offsets =
        node_->declare_parameter<std::vector<double>>("SERVO_OFFSET_DEG", std::vector<double>());

    std::vector<bool> clockwise =
        node_->declare_parameter<std::vector<bool>>("SERVO_ORIENTATION_CLOCKWISE", std::vector<bool>());

    std::vector<int64_t> ids =
        node_->declare_parameter<std::vector<int64_t>>("SERVO_SERIAL_ID", std::vector<int64_t>());

    size_t numServos = names.size();
    if (adaptations.size() < numServos || offsets.size() < numServos || clockwise.size() < numServos ||
        ids.size() < numServos) {
        RCLCPP_ERROR(node_->get_logger(),
                     "CServoController: Parameter size mismatch! SERVO_NAME: %zu, "
                     "SERVO_ADAPTATION_DEG: %zu, SERVO_OFFSET_DEG: %zu, "
                     "SERVO_ORIENTATION_CLOCKWISE: %zu, SERVO_SERIAL_ID: %zu",
                     names.size(), adaptations.size(), offsets.size(), clockwise.size(), ids.size());
        numServos =
            std::min({names.size(), adaptations.size(), offsets.size(), clockwise.size(), ids.size()});
    }

    for (size_t i = 0; i < numServos; ++i) {
        servos_[i] = CServo{names[i], static_cast<uint8_t>(ids[i]), clockwise[i], offsets[i], adaptations[i]};
        nameToIdx_[names.at(i)] = i;
    }

    protocol_ = createServoProtocol(node_, serialPort, isServoControllerOffline, servoControllerType);
    if (!protocol_) {
        return;
    }

    if (!protocol_->triggerConnection()) {
        RCLCPP_WARN_STREAM(node_->get_logger(), "CServoController: connection FAILED");
        return;
    }
    RCLCPP_INFO_STREAM(node_->get_logger(), "CServoController: connection successful");

    // wait 500ms for servos to be ready
    std::this_thread::sleep_for(std::chrono::milliseconds(500));

    subSingleServoRequest_ = node_->create_subscription<ServoAngle>(
        "single_servo_request", 10, std::bind(&CServoController::onSingleServoRequestReceived, this, _1));

    subServoDirectRequest_ = node_->create_subscription<ServoDirectRequest>(
        "servo_direct_request", 10, std::bind(&CServoController::onServoDirectRequestReceived, this, _1));

    pubAngles_ = node_->create_publisher<ServoAngles>("servo_angles", 10);
    pubStatus_ = node_->create_publisher<ServoStatus>("servo_status", 10);
}
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

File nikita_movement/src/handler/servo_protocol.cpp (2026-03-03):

/*******************************************************************************
 * Copyright (c) 2024 Christian Stein
 ******************************************************************************/

#include "handler/servo_protocol.hpp"

#include <fcntl.h>
#include <termios.h>
#include <unistd.h>

#include <algorithm>
#include <cstring>
#include <iostream>
#include <string>

namespace nikita_movement {

static constexpr bool SERIAL_DEBUG = false;

CServoProtocol::CServoProtocol(std::shared_ptr<rclcpp::Node> node, const std::string& deviceName)
    : node_(node), deviceName_(deviceName) {
}

bool CServoProtocol::triggerConnection() {
    isConnected_ = false;

    struct termios options;

    // Open device
    device_ = open(deviceName_.c_str(), O_RDWR | O_NOCTTY | O_NDELAY);
    if (device_ == -1) return false;

    // Optional: switch to blocking mode
    fcntl(device_, F_SETFL, 0);

    // Flush port
    tcflush(device_, TCIOFLUSH);

    // Get current port settings
    if (tcgetattr(device_, &options) < 0) {
        close(device_);
        return false;
    }

    // Set baud rate
    cfsetispeed(&options, B115200);
    cfsetospeed(&options, B115200);

    // 8N1 config
    options.c_cflag &= ~PARENB;
    options.c_cflag &= ~CSTOPB;
    options.c_cflag &= ~CSIZE;
    options.c_cflag |= CS8;
    options.c_cflag &= ~CRTSCTS;
    options.c_cflag |= CREAD | CLOCAL;

    // Raw input/output
    options.c_lflag &= ~(ICANON | ECHO | ECHOE | ISIG);
    options.c_iflag &= ~(IXON | IXOFF | IXANY);
    options.c_iflag &= ~(INLCR | ICRNL | IGNCR);
    options.c_oflag &= ~OPOST;

    // Set timeout to 100 ms (VTIME = 1 means 0.1s)
    options.c_cc[VMIN] = 1;  // Minimum number of characters to read
    options.c_cc[VTIME] = 1;

    // Apply the configuration
    if (tcsetattr(device_, TCSANOW, &options) != 0) {
        close(device_);
        return false;
    }

    isConnected_ = true;
    return true;
}

bool CServoProtocol::isConnected() {
    return isConnected_;
}

void CServoProtocol::closeConnection() {
    close(device_);
}

bool CServoProtocol::writeToServo(uint8_t buf[], int numBytes) {
    ssize_t written = write(device_, buf, numBytes);
    if (written < 0 || written != numBytes) {
        return false;
    }
    if (SERIAL_DEBUG) {
        std::string text = "[";
        for (auto i = 0; i < 6; ++i) {
            text += std::to_string(buf[i]) + ", ";
        }
        // text.replace();
        text += "]";
        RCLCPP_INFO_STREAM(node_->get_logger(), "serial: " << text);
    }
    return true;
}

bool CServoProtocol::readCMD(uint8_t ID, uint8_t CMD_opcode, uint8_t RX_buf_size, uint8_t* RX_buf) {
    uint8_t TX_buf[s_SERVO_ALL_READ_CMDS + 3];
    bool syntax_check = false;

    TX_buf[0] = TX_buf[1] = SERVO_FRAME_HEADER;
    TX_buf[2] = ID;
    TX_buf[3] = s_SERVO_ALL_READ_CMDS;
    TX_buf[4] = CMD_opcode;
    TX_buf[5] = checksum(TX_buf);

    if (!writeToServo(TX_buf, sizeof(TX_buf))) {  // Send Read Command for 'CMD_opcode'
        return false;
    }

    int rx_size = read(device_, RX_buf, RX_buf_size);
    syntax_check = (rx_size == RX_buf_size);
    syntax_check = syntax_check && (RX_buf[0] == SERVO_FRAME_HEADER);
    syntax_check = syntax_check && (RX_buf[1] == SERVO_FRAME_HEADER);
    if (ID != 0xFE)  // Broadcast Read CMD returns real ID
    {
        syntax_check = syntax_check && (RX_buf[2] == ID);
    }
    syntax_check = syntax_check && (RX_buf[3] == RX_buf_size - 3);
    syntax_check = syntax_check && (RX_buf[4] == CMD_opcode);
    syntax_check = syntax_check && (RX_buf[RX_buf_size - 1] == checksum(RX_buf));

    return syntax_check;
}

uint8_t CServoProtocol::checksum(uint8_t buf[]) {
    uint8_t i;
    uint16_t chksum = 0;
    for (i = 2; i < buf[3] + 2; i++) {
        chksum += buf[i];
    }
    chksum = ~chksum;
    i = (uint8_t)chksum;
    return i;
}

bool CServoProtocol::getServoID(uint8_t ID, uint8_t& answer) {
    uint8_t CMD_opcode = SERVO_ID_READ;
    uint8_t RX_buf[s_SERVO_ID_READ + 3];
    bool syntax_check = readCMD(ID, CMD_opcode, sizeof(RX_buf), RX_buf);
    if (syntax_check) {
        answer = RX_buf[5];  // The servo ID is in the 6th byte of the response
    }
    return syntax_check;
}

bool CServoProtocol::setServoID(uint8_t ID, uint8_t newID) {
    uint8_t buf[s_SERVO_ID_WRITE + 3];

    newID = std::clamp<uint8_t>(newID, 0, 254);  // ID must be in range 0..254
    buf[0] = buf[1] = SERVO_FRAME_HEADER;
    buf[2] = ID;
    buf[3] = s_SERVO_ID_WRITE;
    buf[4] = SERVO_ID_WRITE;
    buf[5] = newID;
    buf[6] = checksum(buf);

    return writeToServo(buf, sizeof(buf));
}

bool CServoProtocol::setPosition(uint8_t ID, uint16_t pos, uint16_t time) {
    uint8_t buf[s_SERVO_MOVE_TIME_WRITE + 3];

    pos = std::clamp<uint16_t>(pos, 0, 1000);
    time = std::clamp<uint16_t>(time, 0, 30000);  // time is in ms

    buf[0] = buf[1] = SERVO_FRAME_HEADER;
    buf[2] = ID;
    buf[3] = s_SERVO_MOVE_TIME_WRITE;
    buf[4] = SERVO_MOVE_TIME_WRITE;
    buf[5] = getLowByte(pos);
    buf[6] = getHighByte(pos);
    buf[7] = getLowByte(time);
    buf[8] = getHighByte(time);
    buf[9] = checksum(buf);

    return writeToServo(buf, sizeof(buf));
}

bool CServoProtocol::setRegPos(uint8_t ID, uint16_t pos, uint16_t time) {
    uint8_t buf[s_SERVO_MOVE_TIME_WAIT_WRITE + 3];

    pos = std::clamp<uint16_t>(pos, 0, 1000);
    time = std::clamp<uint16_t>(time, 0, 30000);  // time is in ms

    buf[0] = buf[1] = SERVO_FRAME_HEADER;
    buf[2] = ID;
    buf[3] = s_SERVO_MOVE_TIME_WAIT_WRITE;
    buf[4] = SERVO_MOVE_TIME_WAIT_WRITE;
    buf[5] = getLowByte(pos);
    buf[6] = getHighByte(pos);
    buf[7] = getLowByte(time);
    buf[8] = getHighByte(time);
    buf[9] = checksum(buf);

    return writeToServo(buf, sizeof(buf));
}

bool CServoProtocol::actionStart(uint8_t ID) {
    uint8_t buf[s_SERVO_MOVE_START + 3];

    buf[0] = buf[1] = SERVO_FRAME_HEADER;
    buf[2] = ID;
    buf[3] = s_SERVO_MOVE_START;
    buf[4] = SERVO_MOVE_START;
    buf[5] = checksum(buf);

    return writeToServo(buf, sizeof(buf));
}

bool CServoProtocol::moveStop(uint8_t ID) {
    uint8_t buf[s_SERVO_MOVE_STOP + 3];

    buf[0] = buf[1] = SERVO_FRAME_HEADER;
    buf[2] = ID;
    buf[3] = s_SERVO_MOVE_STOP;
    buf[4] = SERVO_MOVE_STOP;
    buf[5] = checksum(buf);

    return writeToServo(buf, sizeof(buf));
}

bool CServoProtocol::getPositionOffset(uint8_t ID, int8_t& deviation) {
    uint8_t CMD_opcode = SERVO_ANGLE_OFFSET_READ;
    uint8_t RX_buf[s_SERVO_ANGLE_OFFSET_READ + 3];
    bool syntax_check = readCMD(ID, CMD_opcode, sizeof(RX_buf), RX_buf);
    // The deviation is stored as an unsigned byte (0..255), but represents a signed value (-128..+127)
    if (syntax_check) {
        uint8_t raw = RX_buf[5];
        if (raw > 127) {
            deviation = static_cast<int8_t>(raw) - 127;
        } else {
            deviation = static_cast<int8_t>(raw);
        }
    }
    return syntax_check;
}
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

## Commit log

2025-09-30 add code base
    [config.txt, servo_description.yaml]
2025-10-10 add parsing of leg angles to and from actionpackagesparser
2025-10-11 replace actionpackages.json with actionpackages.yaml
    [requester.cpp]
2025-10-14 first try of a kinematic UT
2025-10-25 move servo_controller to nikita_movement and call it directly
    [servo_description.yaml]
2025-10-26 fix kinematics function setLegAngles()
    [requester.cpp]
2025-10-29 fix error of not executing servo command
    [servohandler.cpp]
2025-10-29 fix error of not executing servo command v2
    [servohandler.cpp]
2025-10-29 fix error of not executing servo command v3
    [servohandler.cpp]
2025-10-29 fix error of not executing servo command v4
    [servohandler.cpp]
2025-10-29 small fix for highFive
    [requester.cpp]
2025-10-30 change interface for servocontroller.cpp, delete old node servocontroller
    [servo_description.yaml]
2025-11-26 new moveBody() function that sets all joint values
2025-12-04 set callback to receive the initial servo angles
2025-12-05 fix gait leg wave
2026-01-10 work on laydown and standup
    fix test_helpers files
    add gaits for neutral and calibrate
    fix state tripod
    stop standup and laydown if it is already in the requested position
    activate duration for laydown and standup
    remove actionpackageparser from movement
    fix left and right mixup
    nikita_movement/config/anatomy.yaml
    invert joystick axes
    fix head yaw direction
    add more setup descriptions
    small fix
    fix music player
    change relay pin, add pinlayout to readme
    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
    [servo_description.yaml]
2026-01-12 update the autostart service file, debounce the start button
2026-01-12 do not evaluate the servo status if the relay is off
2026-01-21 change filtering of the velocity for tripod
2026-01-25 activate lidar, deactivate kinematics logging
2026-01-25 add launch file for lidar
2026-03-07 add LIDARLite library as git submodule
2026-03-07 refactor(nikita_brain): modernize to C++23 — auto-generate reverse map, replace void* with json&, use std::format/ranges/to_underlying/contains
2026-03-15 add new movementType MOVE depending on the velocity
2026-03-15 add files for simulation and rviz
    [empty.sdf, inertia.xacro, joint_controllers.yaml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]
2026-03-22 fix rviz and gazebo
    [requester.cpp]
2026-03-27 small fixes
    [inertia.xacro, nikita.urdf.xacro]
2026-03-27 add lidar and imu to the model
    [nikita.urdf.xacro]
2026-03-30 remove filter, solo hysteresis is fine
2026-04-03 added navigation
    [nikita.urdf.xacro, simple_room.sdf]
2026-04-17 fix the velocity of the gait switches
2026-05-28 support for feetech added
    [servo_description.yaml]
2026-06-28 add build123d example
    [hex_with_hole.dxf, hex_with_hole.step, hex_with_hole.stl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]
2026-06-29 added 2d and 3d leg and servo
    [HX-35H Botton Bracket.STEP, HX-35H Side Bracket.STEP, HX-35H Straight U Bracket.STEP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]
2026-06-29 make spacers variable
2026-07-01 add marker to the leg
    [leg_top.dxf, leg_top.step]
2026-07-06 created a leg with spacer and connection
    [assembly_leg_with_connection_and_spacer.step, leg_connection.dxf, leg_connection.step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]
2026-07-08 added body layouts
    [body_layer_0.dxf, body_layer_0.step, body_layer_1.dxf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]
2026-07-10 update the assembly_foot
    [assembly_foot.step, assembly_leg_with_connection_and_spacer.step, foot_back.dxf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]
2026-07-14 refactor body_layer
    [body_layer_0.dxf, body_layer_0.step, body_layer_1.dxf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]
2026-07-19 generalize body_layers
    [body_layer_1.dxf, body_layer_1.step]
2026-07-20 add assembly_body.py
    [assembly_foot.step, assembly_leg_cylinders.step, assembly_leg_with_connection_and_spacer.step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]
2026-07-27 add servo connection holes
2026-08-07 finish assembly_tibia, add first version of inclined_bracket and assembly_femur
2026-08-10 add assembly_coxa and brackets
2026-08-18 added simplified servo
2026-09-07 update simplified servo, add servos to body
2026-09-07 first version of the complete assembly
2026-09-07 legs are connected correctly
2026-09-07 fix the complete assembly
2026-09-08 add joints, add test for coaxial assembly
2026-09-08 add joint to bracket_u_shape
2026-09-08 fix the size of the brackets
2026-09-08 create assembly leg
2026-09-08 fix assembly_leg.py
2026-09-08 fxed assembly_complete
2026-09-09 started with the head cad
2026-09-09 add boards
2026-09-09 add rpi5 board
2026-09-09 added servo plug boards
2026-09-09 add relay
2026-09-10 arrange boards
2026-09-10 add servo interface board
2026-09-10 added i2c distributor board
2026-09-10 move cad files to nikita_description
    [HX-35H Botton Bracket.STEP, HX-35H Side Bracket.STEP, HX-35H Straight U Bracket.STEP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]
2026-09-10 add assembly complete as the conjunction of coxa, femur and tibia
    [assembly_head.stl, mesh_leg.xacro, nikita_mesh.urdf.xacro]
2026-09-11 head added to assembly_complete
2026-09-11 some fixes for the mesh assembly
    [assembly_head.stl, mesh_leg.xacro]
2026-09-11 further improvement of the mesh assignment
    [mesh_leg.xacro]
